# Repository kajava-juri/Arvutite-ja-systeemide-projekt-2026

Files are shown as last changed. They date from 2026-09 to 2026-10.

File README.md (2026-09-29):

# Arvutite-ja-systeemide-projekt-2026

**Pressure Control mock-up**
A closed-loop control system for regulating air pressure to a configurable setpoint by driving a fan.

## Overview

#### Block diagram

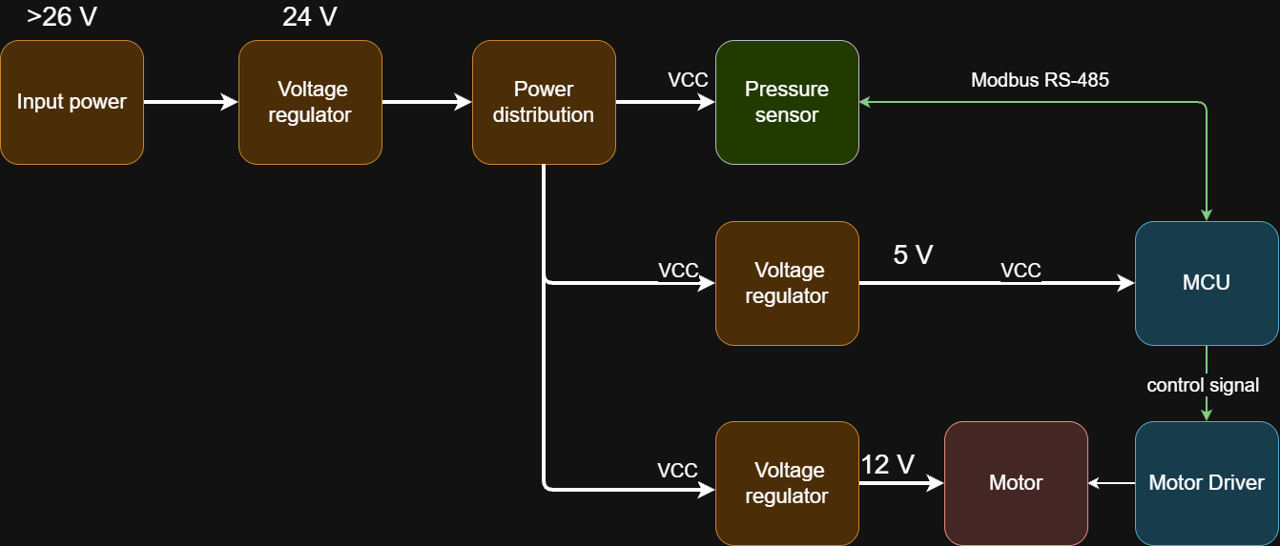
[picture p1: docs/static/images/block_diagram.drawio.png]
Block Diagram

## Project structure

- docs - contains documentation markdown files
- src - firmware code folder
- schematics - diagrams and KiCad projects

## Wiring

### MAX485 module wiring for the prototype

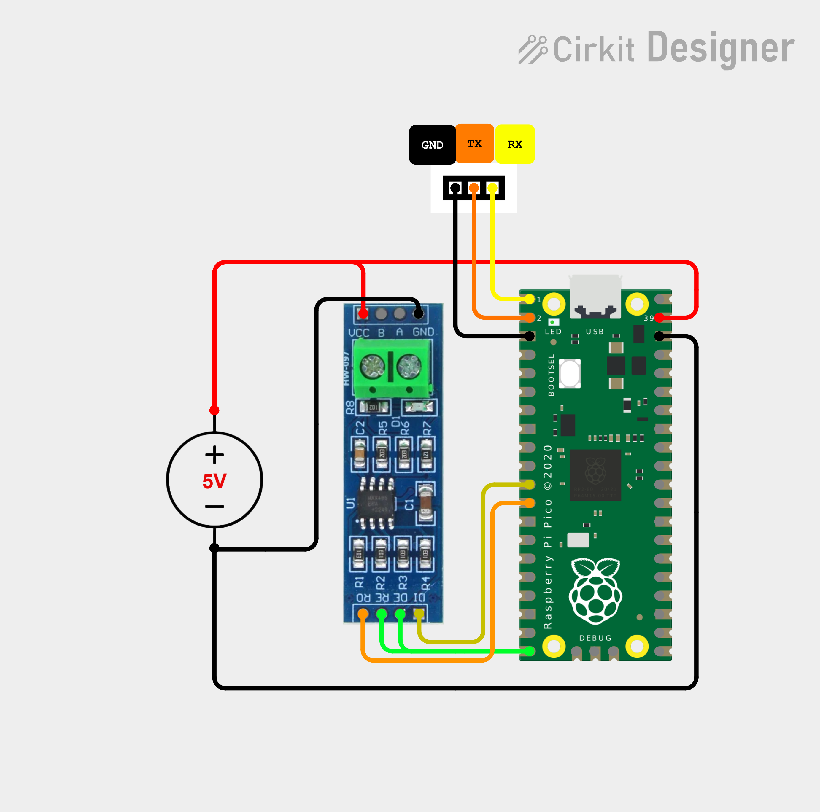
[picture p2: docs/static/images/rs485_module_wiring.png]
MAX485 module wiring


## Documentation

-  [components](docs/components.md) - bill of materials, links, vendors and prices
- [qbm68-sensor](docs/qbm68-sensor.md) - documentation on the siemens sensor, usage in the project, troubleshooting, etc...
- [fan-control](docs/fan-control.md) - fan control solutions, schematics
- [power](docs/power.md) - regulator and voltage rails

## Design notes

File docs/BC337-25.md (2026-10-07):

### Fan switch: BC337-25 

Load: 12 V fan, 0.1 A

### 1. Base resistor

Minimum base current for saturation:

    Ib(min) = Ic / hFE = 100 mA / 160 = 0.63 mA

Design for a safety factor of about 4x, so Ib is about 2.5 mA:

    Rb = (V_GPIO - V_BE) / Ib = (3.3 V - 0.8 V) / 2.5 mA = 1.0 kOhm

Saturation check (forced gain must be well below hFE):

    beta_forced = Ic / Ib = 100 mA / 2.5 mA = 40  <  160  

### 2. Power dissipation

Base resistor:

    P_Rb = Ib^2 * Rb = (2.5 mA)^2 * 1 kOhm = 6.25 mW  

Collector-emitter loss:

    P_CE = V_CE(sat) * Ic = 0.1 V * 0.1 A = 10 mW

Base-emitter loss:

    P_BE = V_BE * Ib = 0.8 V * 2.5 mA = 2 mW   
 
Total transistor dissipation:

    P_d = P_CE + P_BE = 10 + 2 = 12 mW   

Fan supply voltage:

    V_fan = 12 V - V_CE(sat) = 11.9 V 

### 3. Thermal calculation

    T_j = T_a + P_d * R_thJA
    25 °C + 12 mW * 200 = 27.4 °C  

Maximum allowed power at a given ambient temperature:

    P_max = (T_j(max) - T_a) / R_thJA
    P_max(25 °C) = (150 - 25) / 200 = 625 mW
    P_max(60 °C) = (150 - 60) / 200 = 450 mW

the transistor dissipates under 20 mW, which is more than 20x below the limit even at 60 °C ambient so no heatsink is needed.

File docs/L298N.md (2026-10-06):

## Fan switch: L298N module

Load: 12 V fan, 0.1 A

### 1. Voltage across the fan

    V_fan = Vs - V_drop = 12 V - 1.8 V = 10.2 V

The fan runs at about 85 % of its nominal voltage.

### 2. Power dissipation

Output stage:

    P_out = V_drop * I_L = 1.8 V * 0.1 A = 0.18 W

Quiescent power (upper estimate):

    P_Vs  = Vs * Is  = 12 V * 36 mA = 0.43 W
    P_Vss = Vss * Iss = 5 V * 13 mA = 0.065 W

Total:

    P_tot = 0.18 + 0.43 + 0.065 = 0.675 W

 the 5 V on the module (Vss) is produced by the on-board 78M05 from Vs when the 5V-EN jumper is fitted. Part of this loss is dissipated in the regulator, not in the L298.

### 3. Thermal calculation

R_thJA with a heatsink :

    R_thJA = R_thJC + R_th(case-sink) + R_th(sink-ambient)
           = 3 + 1 + 20 = 24 °C/W   (estimate for the small L298N board heatsink. The heatsink value is not given by the manufacturer.) 

Maximum power:

    P_max = (T_j(max) - T_a) / R_thJA
    P_max = (130 - 25) / 24 = 4.4 W

    T_j = T_a + P_tot * R_thJA
    25 + 0.675 * 24 = 41.2 °C

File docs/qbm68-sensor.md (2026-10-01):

## Interfaces

- **Analog** - voltage/current output proportional to pressure (0-10 V / 4-20 mA)
- **Modbus RTU (RS-485)** - digital read of pressure value from register

### Modbus RS-485

Modbus RS-485 uses differential signaling over twisted pair. For the differential signal to perform better, a [twisted pair](https://en.wikipedia.org/wiki/Twisted_pair) wiring is used. 
- data rate is up to 10 Mbit/s
	- and at lower speeds, distances can reach up to 1200 meters.[^rs485] 
- As a rule of thumb, the speed in bit/s multiplied by the length in meters should not exceed $10^8$. Thus, a 50-meter cable should not signal faster than 2 Mbit/s.

#### Bus settings

**baud:**
- default - 9600, 1 stop bit, no parity
- range - 1200 - 56000

Bit sequence: \[ START | 1 | 2 | 3 | 4 | 5 | 6 | 7 |  8 | STOP | STOP \]

#### Register map

For now refer to the datasheet [994020910_911913 N1910en1_QBM68xx.pdf](datasheets/994020910_911913_N1910en1_QBM68xx.pdf)

### Reading over analog

info on how to read over analog, for now refer to the datasheet [994020910_911913 N1910en1_QBM68xx.pdf](datasheets/994020910_911913_N1910en1_QBM68xx.pdf)

---
[^rs485]: [Wikipedia: RS-485](https://en.wikipedia.org/wiki/RS-485)

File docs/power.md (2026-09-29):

Documentation on the power solutions used, reference the block diagram.
### Input Voltage Regulation

#### Prototype
IC regulator with minimal configuration:
### [MC7824CT](https://www.mouser.com/catalog/specsheets/mc7800-d.pdf)

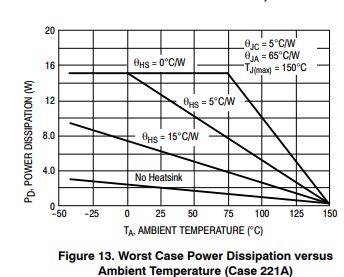
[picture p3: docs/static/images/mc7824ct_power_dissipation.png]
Power dissipation to ambient temperature


With no heatsink at 50 degrees 1.8 W dissipation is the worst case. Using $\theta_{JA}$ = $65 \degree C/W$ and $\theta_{JC} = 5 \degree C/W$, summing them up gives $70 \degree C/W$ and headroom of $80 \degree C/W$. Considering the 12 V mock-up fan speed at maximum takes (depending on the fan):
- fan motor - 200 mA - 500 mA
- qbm68 sensor - 25 mA
- Pico 2 microcontroller 40 mA (over 100 mA when using radio)

Assuming a powerful fan and no radio that would be 600 mA. A linear regulator of more than 3 V would need a heatsink. 

#### PCB

PCB design would work from wall socket and we are not certified to handle 240 VAC and its out of scope of this project. We assume a barrel jack 24 VDC input.
- https://www.amazon.com/LEDwholesalers-100-240V-5-5x2-1mm-Converter-3206-24V/dp/B002LMQ6G2?th=1

Another option to consider is using a miniature 240 VAC converter such as these from MEAN WELL
- https://www.mouser.ee/en/ProductDetail/MEAN-WELL/IRM-15-24?qs=WkdRfq4wf1PZSEWhZtKDbQ%3D%3D

### Fan voltage regulation (Prototype only)

*IN PROGRESS!*

TI webtool for finding suitable buck regulator solutions: [WEBENCH](https://www.ti.com/tool/WEBENCH-CIRCUIT-DESIGNER)
### MCU Voltage regulation

*IN PROGRESS!*

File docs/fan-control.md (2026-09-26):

The actuator in the pressure control loop. Common computer fans (12/24 V).

**Control methods:**
- **Voltage control** - regulate supply voltage to set fan speed. Works on almost any fans.
- **PWM control** - ~25 kHz logic-level PWM to a 4-pin fan's control pin. PWM pin is usually 5 V logic.

**Pin configurations:**
- **2-pin** - power, ground
- **3-pin** - power, ground, tach (RPM feedback).
- **4-pin** - adds PWM control pin.

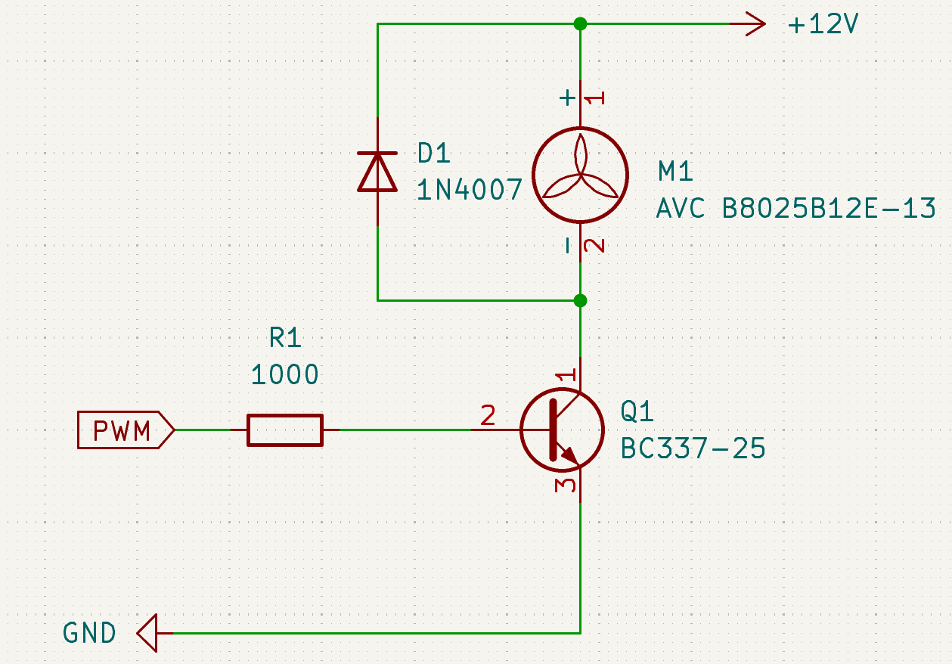
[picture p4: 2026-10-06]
docs/KiCad schematics/Screenshot 2026-10-06 025633.png

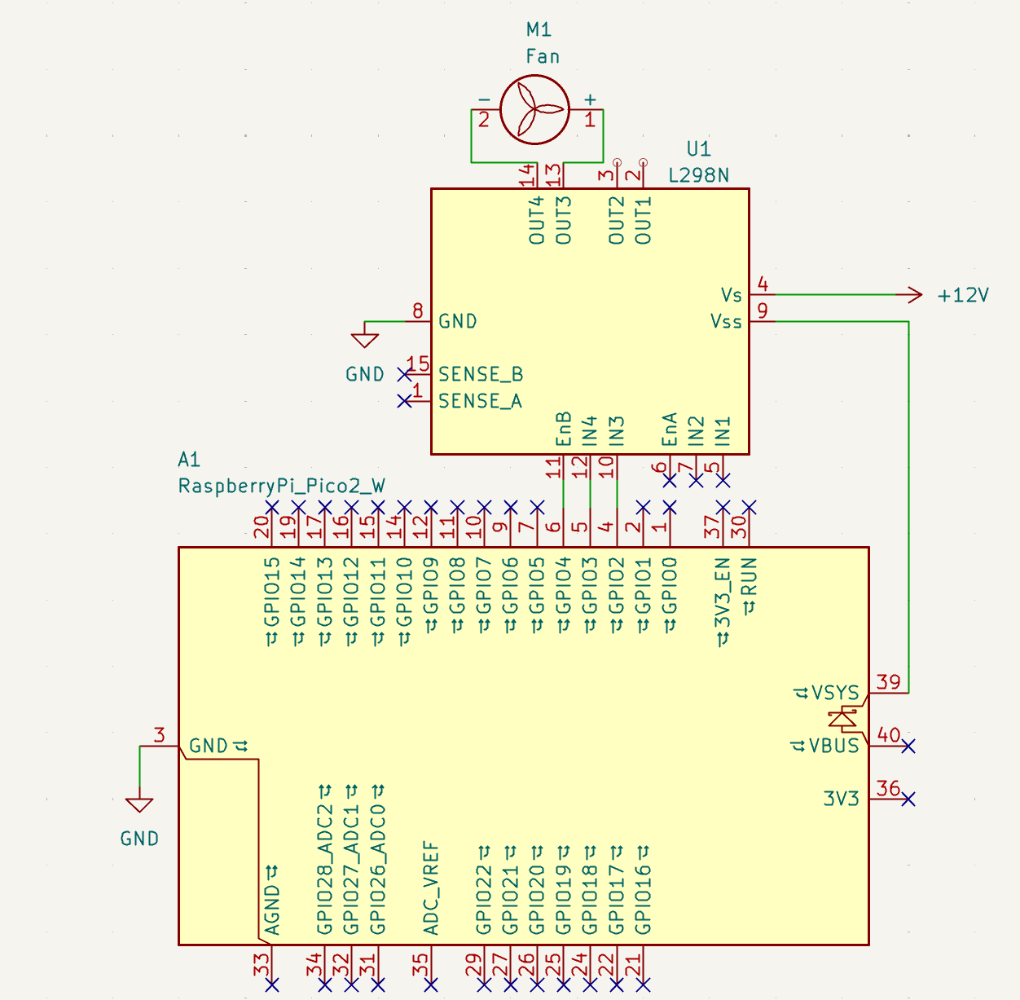
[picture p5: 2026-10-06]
docs/KiCad schematics/Screenshot 2026-10-05 214339.png

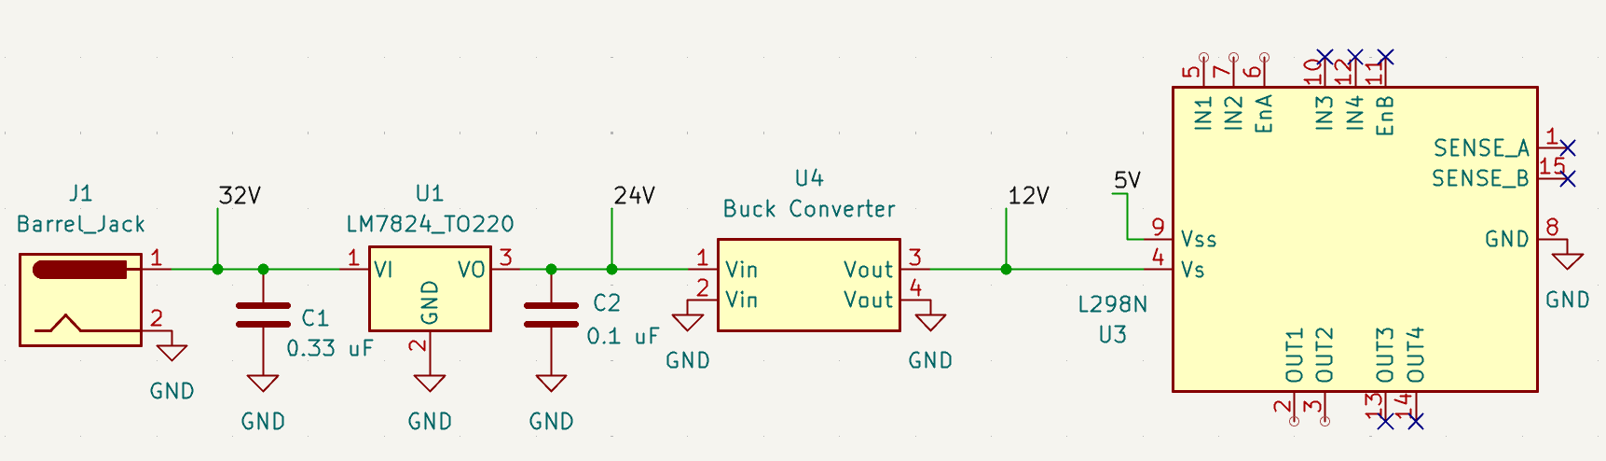
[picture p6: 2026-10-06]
docs/KiCad schematics/Screenshot 2026-10-05 215448.png

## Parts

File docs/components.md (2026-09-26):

Description of protocols, components choice, and modules used. For the overview refer to the [[README.md]],

**RS485 IC transceiver modules:**

| Transceiver | Duplex | Module | Vendor | Link |
| --- | --- | --- | --- | --- |
| [MAX485](https://www.analog.com/en/products/max485.html) | half-duplex | USB | satkit | [link](https://satkit.ee/usb-rs485-muundur-plc-jaoks-max485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) |
| [MAX485](https://www.analog.com/en/products/max485.html) | half-duplex | USB | oomipood  | [link](https://www.oomipood.ee/en/product/oky3406_6_usb_rs485_uleminek_kuni_6mbps_1200m?ref=product_also_bought) |
| [MAX485](https://www.analog.com/en/products/max485.html) | half-duplex | serial | satkit | [link](https://satkit.ee/max485-ttl-rs485-adapter-arduino-ja-raspberry-pi-jaoks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) |
| [MAX485](https://www.analog.com/en/products/max485.html) | half-duplex | serial | | |
| [SN75176](https://www.ti.com/lit/ds/symlink/sn75176a.pdf?ts=1789015653049) | | | | |
| SP3485 | | serial | waveshare | [link](https://www.waveshare.com/wiki/Pico-2CH-RS485) |

## Fan / Actuator

**Pin configurations:**
- **2-pin** - power, ground
- **3-pin** - power, ground, tach (RPM feedback).
- **4-pin** - adds PWM control pin.

| Fan | Voltage | Pins  | Control | Static pressure |
| --- | --- | ----- | --- | --- |
| | 12 V | 4-pin | PWM | |
| | 24 V | 4-pin | PWM | |
| | 12 V | 3-pin | voltage | |
| | 24 V | 3-pin | voltage | |
| | 12 V | 2-pin | voltage | |
| | 24 V | 2-pn  | voltage | |

## Microcontroller

### Requirements

#### Memory
xxx

#### Peripherals

- 1 UART bus
- 1 PWM GPIO pin (> 20 kHz)
- 2 digital for MAX485 RE/DE or with inverter only 1 needed
- 2-4 user interface pins
	- SPI
	- I2C
	- GPIO

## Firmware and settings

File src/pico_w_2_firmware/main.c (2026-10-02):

#include "main.h"

#include "common.h"
#include "max485.h"
#include <stdio.h>
#include "modbus_rtu.h"

int main()
{
    stdio_init_all();

    // Initialise the Wi-Fi chip
    if (cyw43_arch_init()) {
        uart_puts(UART_ID, "Wi-Fi init failed\n");
        return -1;
    }

    // Example to turn on the Pico W LED
    cyw43_arch_gpio_put(CYW43_WL_GPIO_LED_PIN, 1);


    init_gpio_pins();
    max485_init(UART_ID_MAX485);
    max485_set_transmit_mode(TRANSMIT);
    // For more examples of UART use see https://github.com/raspberrypi/pico-examples/tree/master/uart
    ModbusRtuContext ctx = {0};
    modbus_init(&ctx);

    while (true) {
        modbus_state_machine(&ctx);
        sleep_ms(MODBUS_RTU_FRAME_START_END_DELAY_MS * 2);
    }
}

void init_gpio_pins()
{
    // set up UART
    uart_init(UART_ID, BAUD_RATE);
    // set the TX and RX pins by using the function select on the GPIO
    // set datasheet for more information on function select
    gpio_set_function(UART_TX_PIN, GPIO_FUNC_UART);
    gpio_set_function(UART_RX_PIN, GPIO_FUNC_UART);
    
    // UART for MAX485
    uart_init(UART_ID_MAX485, BAUD_RATE_MAX485);
    uart_set_format(UART_ID_MAX485, 8, 1, UART_PARITY_NONE);
    uart_set_hw_flow(UART_ID_MAX485, false, false);
    gpio_set_function(UART_TX_PIN_MAX485, GPIO_FUNC_UART);
    gpio_set_function(UART_RX_PIN_MAX485, GPIO_FUNC_UART);

    gpio_init(RE_DE_PIN);
    gpio_set_dir(RE_DE_PIN, GPIO_OUT);

    uart_puts(UART_ID, "pins initialized\n");
}

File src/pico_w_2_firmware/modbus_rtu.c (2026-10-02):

#include "modbus_rtu.h"
#include "max485.h"
#include <string.h>

int one_request_sent = 0;

// for why the CRC table values are the way they are, refer to modbus specification
// https://www.modbus.org/file/secure/modbusoverserial.pdf

/* Table of CRC values for high–order byte */
static unsigned char auchCRCHi[] = {
    0x00, 0xC1, 0x81, 0x40, 0x01, 0xC0, 0x80, 0x41, 0x01, 0xC0, 0x80, 0x41, 0x00, 0xC1, 0x81,
    0x40, 0x01, 0xC0, 0x80, 0x41, 0x00, 0xC1, 0x81, 0x40, 0x00, 0xC1, 0x81, 0x40, 0x01, 0xC0,
    0x80, 0x41, 0x01, 0xC0, 0x80, 0x41, 0x00, 0xC1, 0x81, 0x40, 0x00, 0xC1, 0x81, 0x40, 0x01,
    0xC0, 0x80, 0x41, 0x00, 0xC1, 0x81, 0x40, 0x01, 0xC0, 0x80, 0x41, 0x01, 0xC0, 0x80, 0x41,
    0x00, 0xC1, 0x81, 0x40, 0x01, 0xC0, 0x80, 0x41, 0x00, 0xC1, 0x81, 0x40, 0x00, 0xC1, 0x81,
    0x40, 0x01, 0xC0, 0x80, 0x41, 0x00, 0xC1, 0x81, 0x40, 0x01, 0xC0, 0x80, 0x41, 0x01, 0xC0,
    0x80, 0x41, 0x00, 0xC1, 0x81, 0x40, 0x00, 0xC1, 0x81, 0x40, 0x01, 0xC0, 0x80, 0x41, 0x01,
    0xC0, 0x80, 0x41, 0x00, 0xC1, 0x81, 0x40, 0x01, 0xC0, 0x80, 0x41, 0x00, 0xC1, 0x81, 0x40,
    0x00, 0xC1, 0x81, 0x40, 0x01, 0xC0, 0x80, 0x41, 0x01, 0xC0, 0x80, 0x41, 0x00, 0xC1, 0x81,
    0x40, 0x00, 0xC1, 0x81, 0x40, 0x01, 0xC0, 0x80, 0x41, 0x00, 0xC1, 0x81, 0x40, 0x01, 0xC0,
    0x80, 0x41, 0x01, 0xC0, 0x80, 0x41, 0x00, 0xC1, 0x81, 0x40, 0x00, 0xC1, 0x81, 0x40, 0x01,
    0xC0, 0x80, 0x41, 0x01, 0xC0, 0x80, 0x41, 0x00, 0xC1, 0x81, 0x40, 0x01, 0xC0, 0x80, 0x41,
    0x00, 0xC1, 0x81, 0x40, 0x00, 0xC1, 0x81, 0x40, 0x01, 0xC0, 0x80, 0x41, 0x00, 0xC1, 0x81,
    0x40, 0x01, 0xC0, 0x80, 0x41, 0x01, 0xC0, 0x80, 0x41, 0x00, 0xC1, 0x81, 0x40, 0x01, 0xC0,
    0x80, 0x41, 0x00, 0xC1, 0x81, 0x40, 0x00, 0xC1, 0x81, 0x40, 0x01, 0xC0, 0x80, 0x41, 0x01,
    0xC0, 0x80, 0x41, 0x00, 0xC1, 0x81, 0x40, 0x00, 0xC1, 0x81, 0x40, 0x01, 0xC0, 0x80, 0x41,
    0x00, 0xC1, 0x81, 0x40, 0x01, 0xC0, 0x80, 0x41, 0x01, 0xC0, 0x80, 0x41, 0x00, 0xC1, 0x81,
    0x40
};

/* Table of CRC values for low–order byte */
static char auchCRCLo[] = {
    0x00, 0xC0, 0xC1, 0x01, 0xC3, 0x03, 0x02, 0xC2, 0xC6, 0x06, 0x07, 0xC7, 0x05, 0xC5, 0xC4,
    0x04, 0xCC, 0x0C, 0x0D, 0xCD, 0x0F, 0xCF, 0xCE, 0x0E, 0x0A, 0xCA, 0xCB, 0x0B, 0xC9, 0x09,
    0x08, 0xC8, 0xD8, 0x18, 0x19, 0xD9, 0x1B, 0xDB, 0xDA, 0x1A, 0x1E, 0xDE, 0xDF, 0x1F, 0xDD,
    0x1D, 0x1C, 0xDC, 0x14, 0xD4, 0xD5, 0x15, 0xD7, 0x17, 0x16, 0xD6, 0xD2, 0x12, 0x13, 0xD3,
    0x11, 0xD1, 0xD0, 0x10, 0xF0, 0x30, 0x31, 0xF1, 0x33, 0xF3, 0xF2, 0x32, 0x36, 0xF6, 0xF7,
    0x37, 0xF5, 0x35, 0x34, 0xF4, 0x3C, 0xFC, 0xFD, 0x3D, 0xFF, 0x3F, 0x3E, 0xFE, 0xFA, 0x3A,
    0x3B, 0xFB, 0x39, 0xF9, 0xF8, 0x38, 0x28, 0xE8, 0xE9, 0x29, 0xEB, 0x2B, 0x2A, 0xEA, 0xEE,
    0x2E, 0x2F, 0xEF, 0x2D, 0xED, 0xEC, 0x2C, 0xE4, 0x24, 0x25, 0xE5, 0x27, 0xE7, 0xE6, 0x26,
    0x22, 0xE2, 0xE3, 0x23, 0xE1, 0x21, 0x20, 0xE0, 0xA0, 0x60, 0x61, 0xA1, 0x63, 0xA3, 0xA2,
    0x62, 0x66, 0xA6, 0xA7, 0x67, 0xA5, 0x65, 0x64, 0xA4, 0x6C, 0xAC, 0xAD, 0x6D, 0xAF, 0x6F,
    0x6E, 0xAE, 0xAA, 0x6A, 0x6B, 0xAB, 0x69, 0xA9, 0xA8, 0x68, 0x78, 0xB8, 0xB9, 0x79, 0xBB,
    0x7B, 0x7A, 0xBA, 0xBE, 0x7E, 0x7F, 0xBF, 0x7D, 0xBD, 0xBC, 0x7C, 0xB4, 0x74, 0x75, 0xB5,
    0x77, 0xB7, 0xB6, 0x76, 0x72, 0xB2, 0xB3, 0x73, 0xB1, 0x71, 0x70, 0xB0, 0x50, 0x90, 0x91,
    0x51, 0x93, 0x53, 0x52, 0x92, 0x96, 0x56, 0x57, 0x97, 0x55, 0x95, 0x94, 0x54, 0x9C, 0x5C,
    0x5D, 0x9D, 0x5F, 0x9F, 0x9E, 0x5E, 0x5A, 0x9A, 0x9B, 0x5B, 0x99, 0x59, 0x58, 0x98, 0x88,
    0x48, 0x49, 0x89, 0x4B, 0x8B, 0x8A, 0x4A, 0x4E, 0x8E, 0x8F, 0x4F, 0x8D, 0x4D, 0x4C, 0x8C,
    0x44, 0x84, 0x85, 0x45, 0x87, 0x47, 0x46, 0x86, 0x82, 0x42, 0x43, 0x83, 0x41, 0x81, 0x80,
    0x40
};

uint16_t compute_crc_simple(uint8_t *message, size_t message_length)
{
    uint16_t crc_reg = 0xFFFF;
    uint16_t polynomial = 0xA001;

    // Exclusive OR the first 8–bit byte of the message with the low–order byte of the 16–bit CRC register, putting the result in the 
    // CRC register.
    // printf("message[0] = 0x%02X\n", message[0]);
    uint8_t lsb;
    for(int i = 0; i < message_length; i++) {
        crc_reg ^= message[i];
        for(int j = 0; j < 8; j++) {    
            lsb = crc_reg & 0x01;
            crc_reg >>= 1;
            if (lsb) {
                crc_reg ^= polynomial;
            }
        }
    }

    return crc_reg;
}

// function code taken from https://www.modbus.org/file/secure/modbusoverserial.pdf
uint16_t compute_crc_fast(uint8_t *message, size_t message_length)
{
    unsigned char uchCRCHi = 0xFF; /* high byte of CRC initialized */
    unsigned char uchCRCLo = 0xFF; /* low byte of CRC initialized */
    unsigned uIndex ; /* will index into CRC lookup table */
    while (message_length--) /* pass through message buffer */
    {
        uIndex = uchCRCLo ^ *message++ ; /* calculate the CRC */
        uchCRCLo = uchCRCHi ^ auchCRCHi[uIndex] ;
        uchCRCHi = auchCRCLo[uIndex] ;
    }
    return (uchCRCHi << 8 | uchCRCLo);
}

void modbus_init(ModbusRtuContext *ctx)
{
    ctx->state = MODBUS_RTU_IDLE;
}

void modbus_action_idle(ModbusRtuContext *ctx)
{
    if(one_request_sent) {
        return;
    }
    uart_puts(UART_ID, "Modbus RTU Idle state\n");
    // char *data = "Hello, Modbus!";
    // modbus_set_slave_address(ctx, (uint8_t)42);
    // modbus_build_request(ctx, 0x03, data, strlen(data));
    // modbus_send_request(ctx);
    modbus_read_from_register(ctx, 0x0000, 1);

    ctx->state = MODBUS_RTU_WAITING_FOR_REPLY;
    uart_puts(UART_ID, "Waiting for reply from slave\n");
    one_request_sent = 1;
}

void modbus_action_waiting_for_reply(ModbusRtuContext *ctx)
{
    max485_set_transmit_mode(RECEIVE);
    // check uart for incoming data
    if (uart_is_readable(UART_ID_MAX485)) {
        // read the reply frame from MAX485
        modbus_read_request(ctx);
        ctx->state = MODBUS_RTU_PROCESSING_REPLY;
    }
}

void modbus_action_processing_reply(ModbusRtuContext *ctx)
{

    // uart_puts(UART_ID, "Processing reply from slave\n");
    // uart_puts(UART_ID, "Slave address: ");
    // uart_putc(UART_ID, ctx->reply.slave_address);
    // uart_puts(UART_ID, "\nFunction code: ");
    // uart_putc(UART_ID, ctx->reply.function_code);
    // uart_puts(UART_ID, "\nData: ");
    // uart_puts(UART_ID, ctx->reply.data);
    // uart_puts(UART_ID, "\nData length: ");
    // char data_length_str[4];
    // snprintf(data_length_str, sizeof(data_length_str), "%d", ctx->reply.data_length);
    // uart_puts(UART_ID, data_length_str);
    // uart_puts(UART_ID, "\n");

    ctx->state = MODBUS_RTU_IDLE;
}

void modbus_action_processing_error(ModbusRtuContext *ctx)
{
    uart_puts(UART_ID, "Error processing reply from slave\n");
}

void modbus_action_turnaround_delay(ModbusRtuContext *ctx)
{
    uart_puts(UART_ID, "Waiting for turnaround delay\n");
}

int modbus_set_slave_address(ModbusRtuContext *ctx, uint8_t slave_address)
{
    ctx->request.slave_address = slave_address;
    return 0;
}
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

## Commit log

2026-09-13 Update links to datasheet in qbm68-sensor.md
2026-09-13 Fix links to datasheet in qbm68-sensor.md
    Updated links in the documentation to point to the correct 'datasheets' directory.
2026-09-18 docs: remove BOM-like info from docs
2026-09-26 updated docs on power regulation design choice
2026-09-26 Fix image path in power.md
    Updated image path for power dissipation chart.
2026-09-26 Fix link to power documentation in README.md
2026-09-28 feat: init max485 driver for simple data transmission
2026-09-28 Add MAX485 module wiring information to README
    Added wiring section for MAX485 module with image.
2026-10-02 feat: add modbus crc calculation and complete the modbus frame structure
2026-10-02 test: send and receive data from mock device using modbus rtu
2026-10-02 fix: increase buffer size for formatted data in modbus_read_request
    [modbus_rtu.c]
2026-10-06 Add documentation for BC337-25 fan switch design
    Documented calculations for base resistor, power dissipation, and thermal management for the BC337-25 transistor used in a fan switch application.
2026-10-06 Create KiCad schematics folder
2026-10-06 Create Fan switch: BC337-25
2026-10-06 Rename Screenshot 2026-10-06 025633.png to Fan switch: BC337-25
2026-10-06 Add documentation for L298N fan switch module
2026-10-09 docs: update overall block diagram and add power budget tree diagram
2026-10-09 Document FQP30N06L fan switch specifications and analysis
    Added detailed analysis and calculations for the FQP30N06L fan switch, including gate drive checks, gate charge, switching time, power dissipation, and thermal calculations.
2026-10-09 Fix formatting and update gate charge time calculation
2026-10-09 Update FQP30N06L.md
    Added calculations for Miller plateau level and K parameter.
2026-10-10 Revise gate charge time calculations in FQP30N06L.md
    Updated calculations for gate charge times and switching loss.
2026-10-10 Update FQP30N06L.md with switching loss details
    Added calculations for switching loss and power dissipation.
2026-10-10 initial cleaner modbus functions with no direct uart calls
2026-10-10 feat: add modbus initial errors and reply timeout handling
    [main.c, modbus_rtu.c]
2026-10-11 rename kicad power folder name
2026-10-15 fix: UART FIFO filling up and causing the blocking function to block and holding the RE/DE pin HIGH
2026-10-18 Add motor control with PWM in core1_main.c
    Implemented motor control functionality with PWM.
2026-10-19 update docs for FQP mosfet with maximum current as function of voltage and BC337-25 thermal LTSpice simulation
2026-10-19 Fix formatting and update calculations in FQP30N06L.md
    Updated the mathematical representation and corrected the formatting in the documentation for the FQP30N06L fan switch.
2026-10-19 Revise switching time and power loss calculations
    Updated calculations for switching time, power losses, and maximum current as a function of voltage in the FQP30N06L documentation.
2026-10-19 Update section header for maximum current function
2026-10-19 add more example for 24 V FQP mosfet power dissipation
2026-10-22 add modbus reply data retrieval feature and a device abstraction that uses the modbus.c abstraction
2026-10-25 add PID implementation files, add inter-core communication of latest sensor value
2026-10-26 feat: initial PID control loop integratied into core 1 process
2026-10-26 prepare the UI integration by adding python-based modbus rtu server and pico firmware files
2026-10-27 feat: add modbus function 0x06 implementation and a device that enables to publish data by writing to specified slave and address
2026-10-27 feat: add optional interface slave structure to qbm68 device
2026-10-31 fix: correct total output calculation and integral adjustment in PID controller
2026-11-02 fix: update rotary_value initialization and adjustment limits in motor control
2026-11-04 update core1 to use pid_controller for motor, experimental
2026-11-06 docs: added power_tree_budget.drawio.xml
